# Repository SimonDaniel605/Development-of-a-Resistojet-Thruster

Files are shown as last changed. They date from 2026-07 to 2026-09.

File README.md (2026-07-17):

# Development of a Resistojet Thruster
This repository contains the design, modelling, simulation, and development of a low-power electrothermal resistojet propulsion system for nanosatellite station-keeping and orbital manoeuvring.

The project forms part of an MEng (Electronic Engineering) research project at Stellenbosch University and focuses on developing a compact, efficient, and manufacturable propulsion system capable of providing precise orbital manoeuvring for future small satellite missions.

The work includes analytical modelling, CFD validation, hardware development, electronics, embedded software, and experimental test infrastructure.

## Author
**Simon Daniel**  
MEng Candidate  
Electronic Systems Laboratory (ESL)  
Department of Electrical and Electronic Engineering  
Stellenbosch University

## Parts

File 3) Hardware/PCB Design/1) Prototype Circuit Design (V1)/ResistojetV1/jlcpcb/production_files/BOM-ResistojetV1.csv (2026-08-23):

Comment | Designator | Footprint | LCSC | Quantity
100 | R10,R12,R16,R17,R18,R19,R2,R20,R21,R22,R23,R4,R6,R8 | R_0603_1608Metric | C22775 | 14
100k | R1,R32 | R_0603_1608Metric | C25803 | 2
100n | C3,C6,C7 | C_0603_1608Metric | C14663 | 3
100n | C10,C11,C12,C13,C17,C18,C22,C28,C29,C30,C31,C32 | C_0402_1005Metric | C1525 | 12
10k | R11,R13,R14,R24,R29,R3,R30,R5,R7,R9 | R_0603_1608Metric | C25804 | 10
10n | C14,C19,C24,C25,C26,C27 | C_0402_1005Metric | C15195 | 6
10u | C8,C9 | C_0805_2012Metric | C15850 | 2
10u | C2 | C_0805_2012Metric | C440198 | 1
120R | FB1,FB2 | L_0603_1608Metric | C14709 | 2
1N5819WS | D10,D11,D12,D13,D14,D15,D8,D9 | D_SOD-323 | C191023 | 8
1k | R33 | R_0603_1608Metric | C21190 | 1
1n | C33 | C_0603_1608Metric | C1588 | 1
1u | C15,C16,C20,C21 | C_0603_1608Metric | C15849 | 4
220n | C23 | C_0603_1608Metric | C21120 | 1
22u | C4,C5 | C_0805_2012Metric | C45783 | 2
330 | R26,R27,R28 | R_0603_1608Metric | C23138 | 3
680R | R15,R34,R35 | R_0603_1608Metric | C23228 | 3
68k | R31 | R_0603_1608Metric | C23231 | 1
AMS1117-3.3 | U1 | SOT-223-3_TabPin2 | C6186 | 1
AO3400A | Q2,Q3,Q4,Q5,Q6,Q7 | SOT-23 | C20917 | 6
AP63205WU | U2 | TSOT-23-6 | C2071056 | 1
LED | D16,D17 | LED_0603_1608Metric | C2286 | 2
LED | D18,D7 | LED_0603_1608Metric | C2290 | 2
SS14 | D3,D4,D5,D6 | D_SMA | C2480 | 4
SW_Push | SW1 | SW-SMD_L3.9-W3.0-P4.45 | C720477 | 1

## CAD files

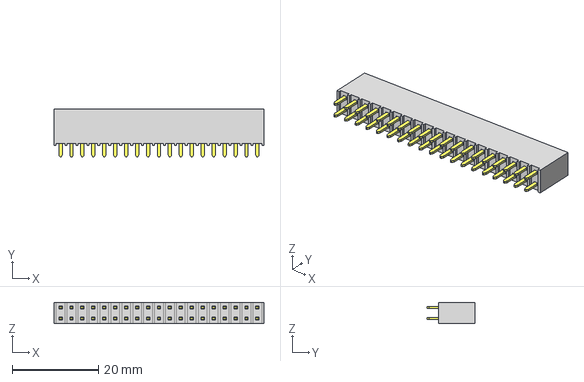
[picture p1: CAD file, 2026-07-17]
3) Hardware/PCB Design/1) Prototype Circuit Design (V1)/Test PCB/ThrusterPrototype/SSW-119-01-F-D.stp
48.8 x 11.2 x 4.95 mm
T1SSW-119-01-F-D
P2SSW-119-01-F-D

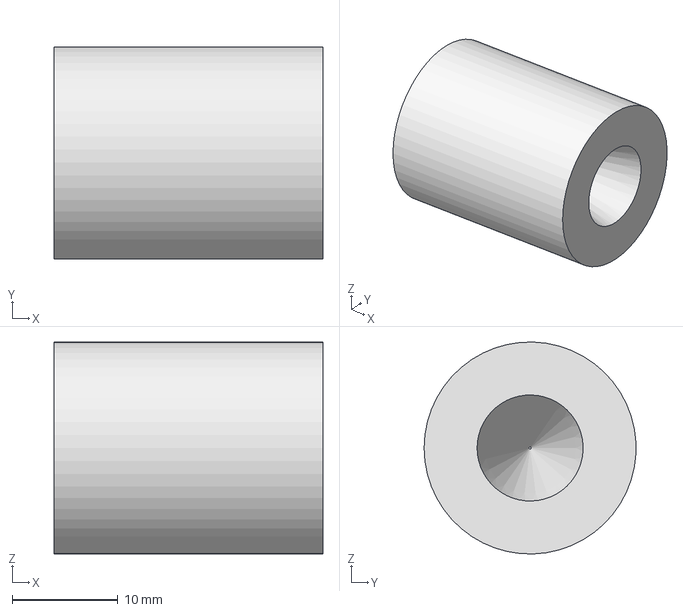
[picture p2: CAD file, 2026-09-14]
3) Hardware/Resistojet Design/ResistojetV2/Nozzle_JLC.step
25.4 x 20.0 x 20.0 mm

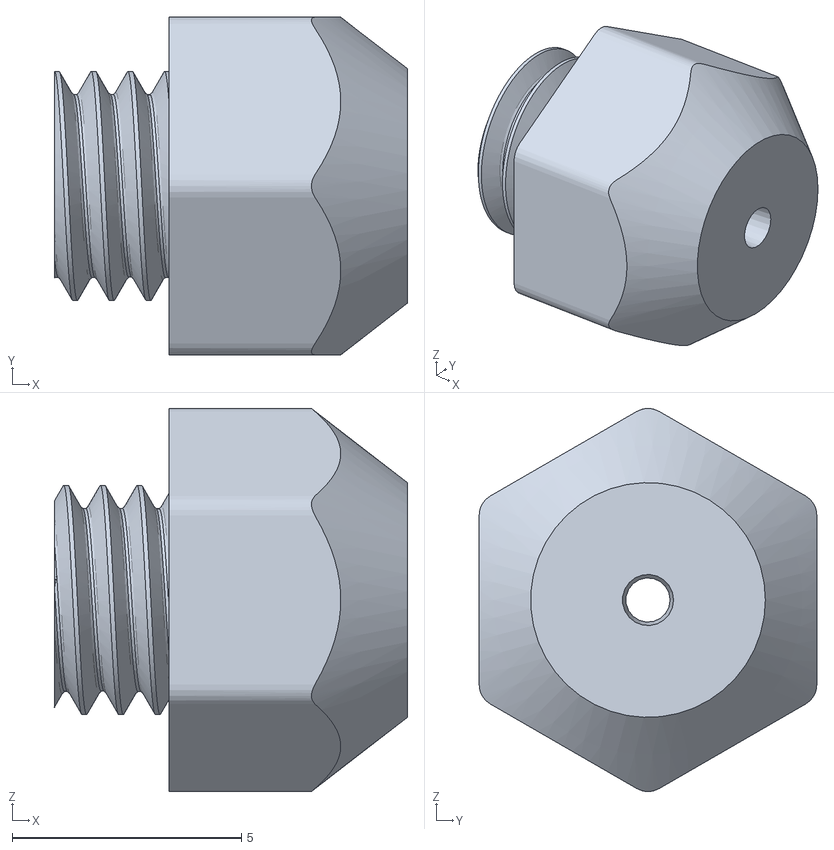
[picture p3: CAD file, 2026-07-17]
3) Hardware/Resistojet Design/Test Nozzles/Jansen's Nozzle Replacements/Redesigned_5.stl
7.69 x 7.36 x 8.35

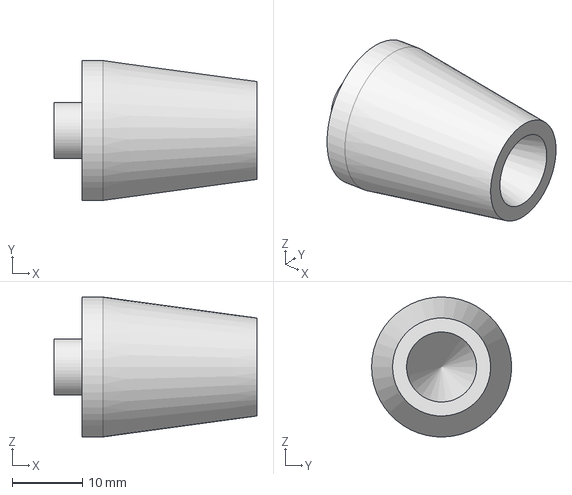
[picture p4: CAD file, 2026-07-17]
3) Hardware/Resistojet Design/Test Nozzles/Nozzle.stp
29.0 x 20.0 x 20.0 mm

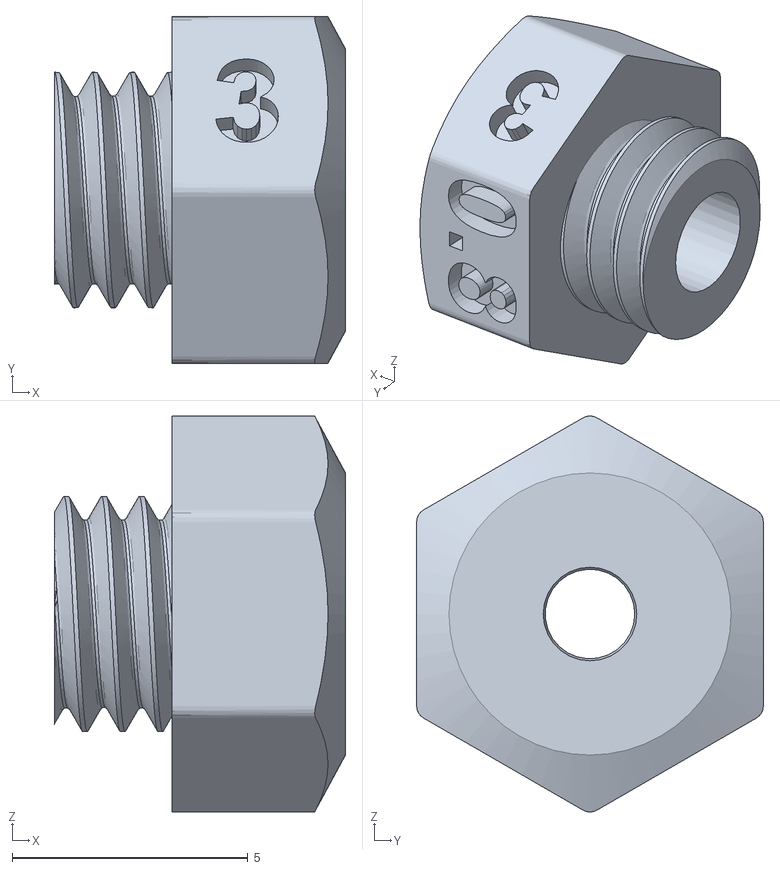
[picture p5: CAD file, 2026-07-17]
3) Hardware/Resistojet Design/Test Nozzles/Test Bench Nozzles/3 bar/Redesigned3_0.8.stl
6.18 x 7.36 x 8.41

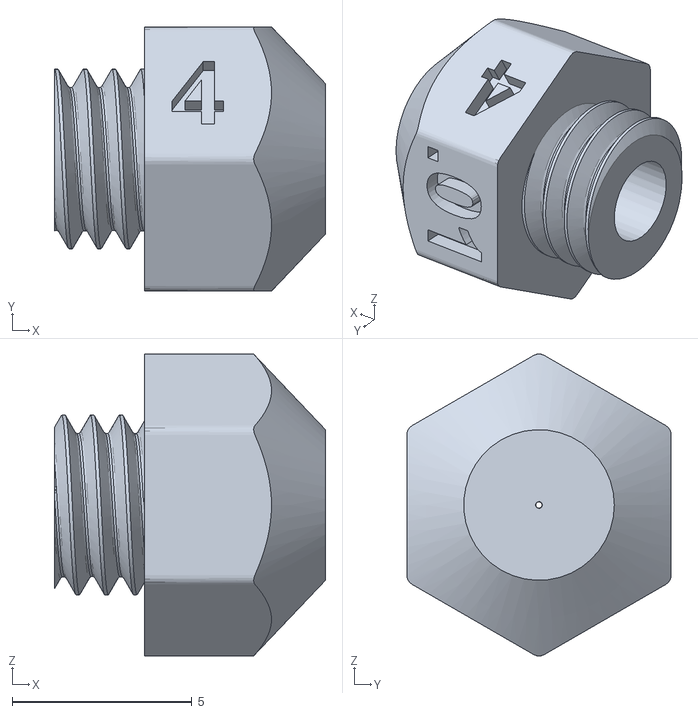
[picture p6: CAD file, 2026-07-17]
3) Hardware/Resistojet Design/Test Nozzles/Test Bench Nozzles/4 bar/Redesigned4_0.01.stl
7.55 x 7.36 x 8.41

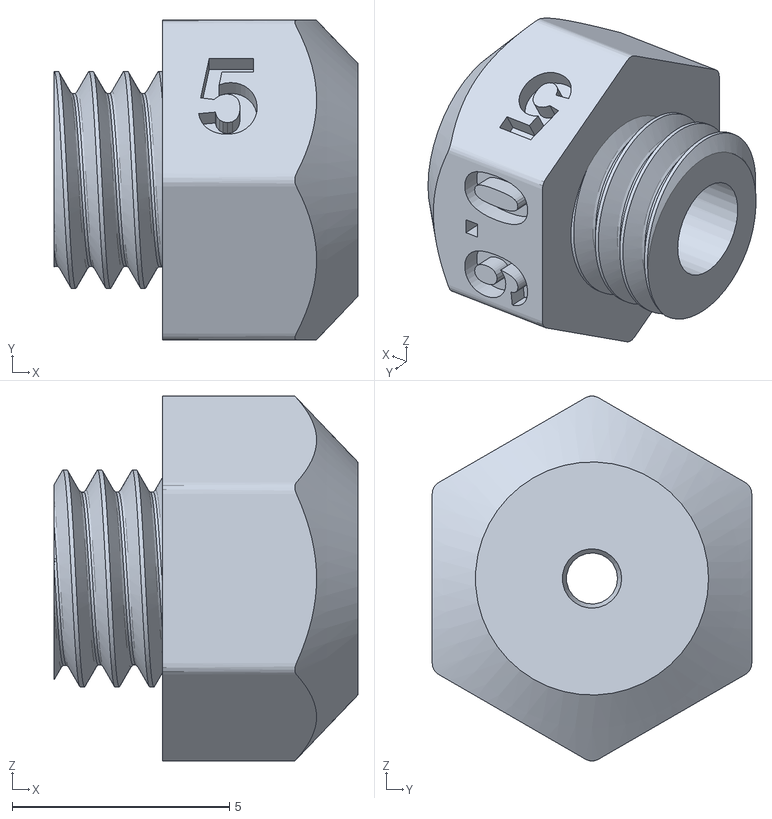
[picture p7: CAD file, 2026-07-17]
3) Hardware/Resistojet Design/Test Nozzles/Test Bench Nozzles/5 bar/Redesigned5_0.6.stl
7.00 x 7.36 x 8.41

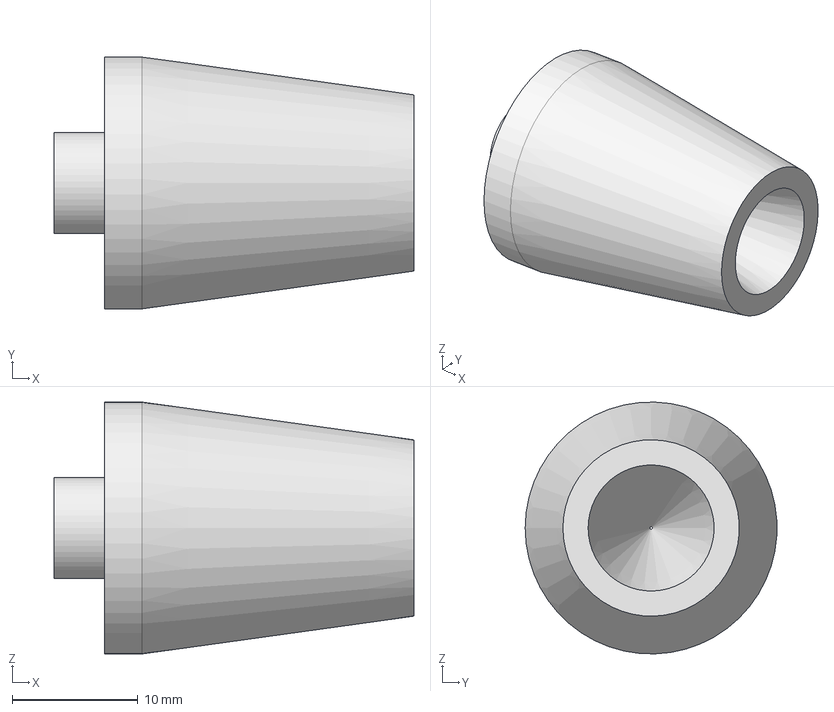
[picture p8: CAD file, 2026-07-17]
3) Hardware/Resistojet Design/ResistojetV2/Nozzle_axial.step
28.6 x 20.0 x 20.0 mm

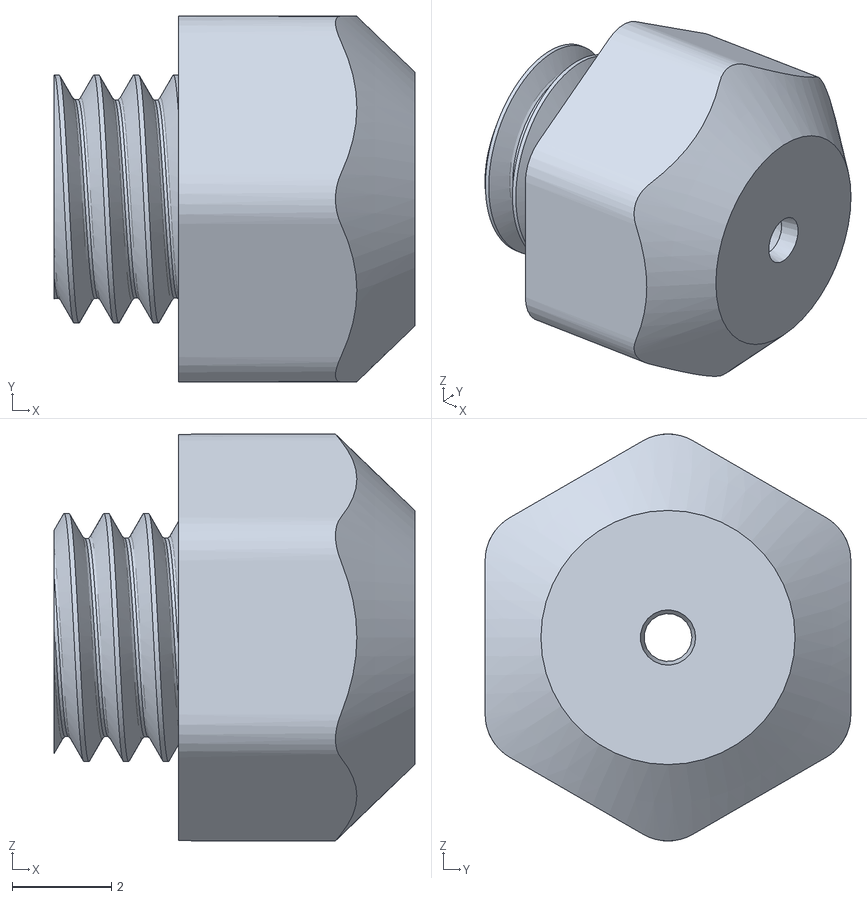
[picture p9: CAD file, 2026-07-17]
3) Hardware/Resistojet Design/Test Nozzles/Jansen's Nozzle Replacements/Redesigned_10.stl
7.26 x 7.36 x 8.19

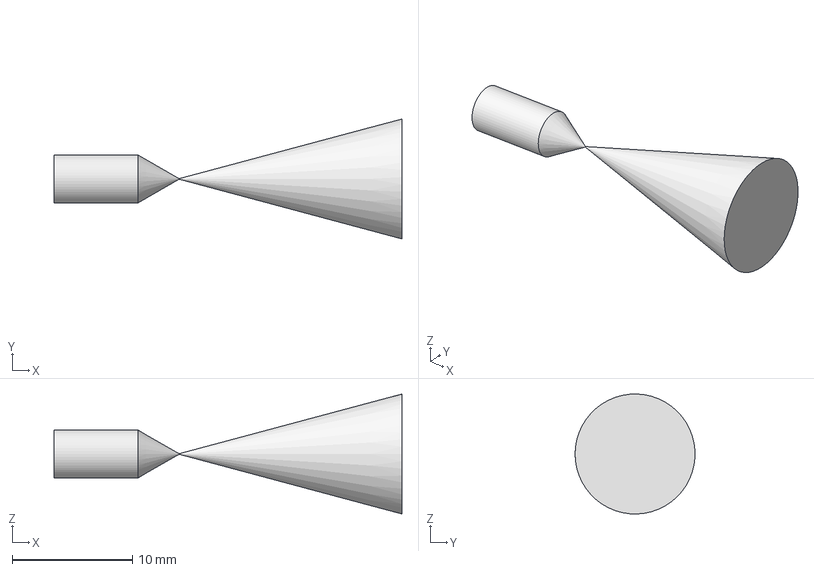
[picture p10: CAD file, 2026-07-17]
3) Hardware/Resistojet Design/Test Nozzles/NozzlePath.stp
29.0 x 9.99 x 10.00 mm

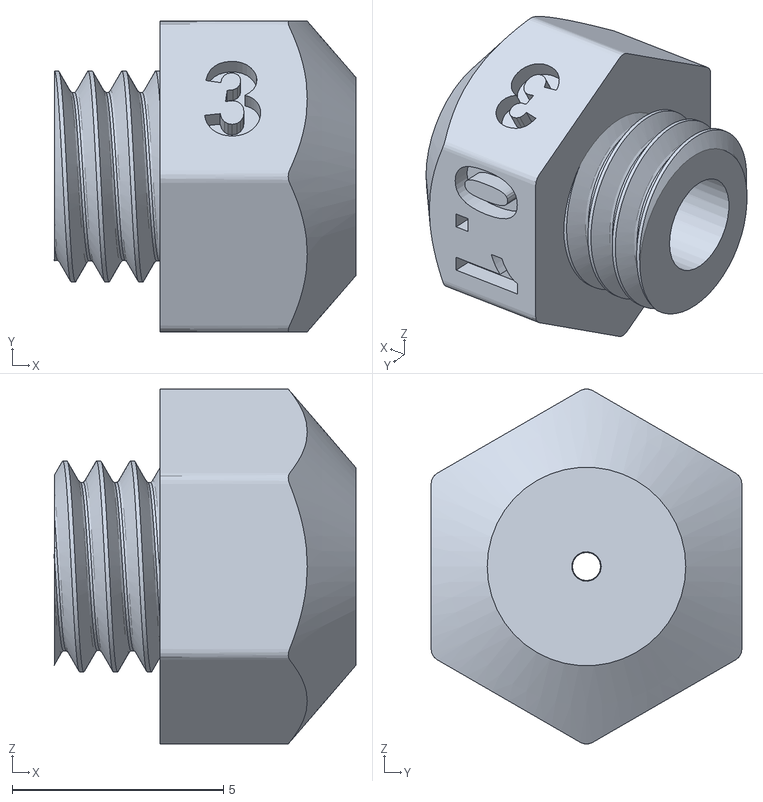
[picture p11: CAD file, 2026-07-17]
3) Hardware/Resistojet Design/Test Nozzles/Test Bench Nozzles/3 bar/Redesigned3_0.1.stl
7.14 x 7.36 x 8.41

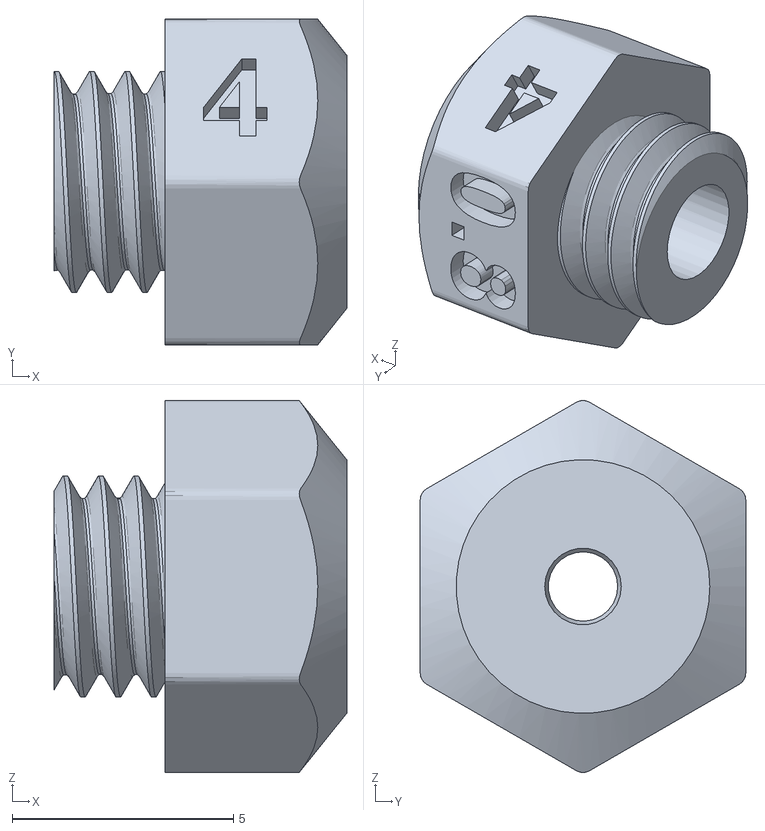
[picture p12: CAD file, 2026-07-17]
3) Hardware/Resistojet Design/Test Nozzles/Test Bench Nozzles/4 bar/Redesigned4_0.8.stl
6.61 x 7.36 x 8.41

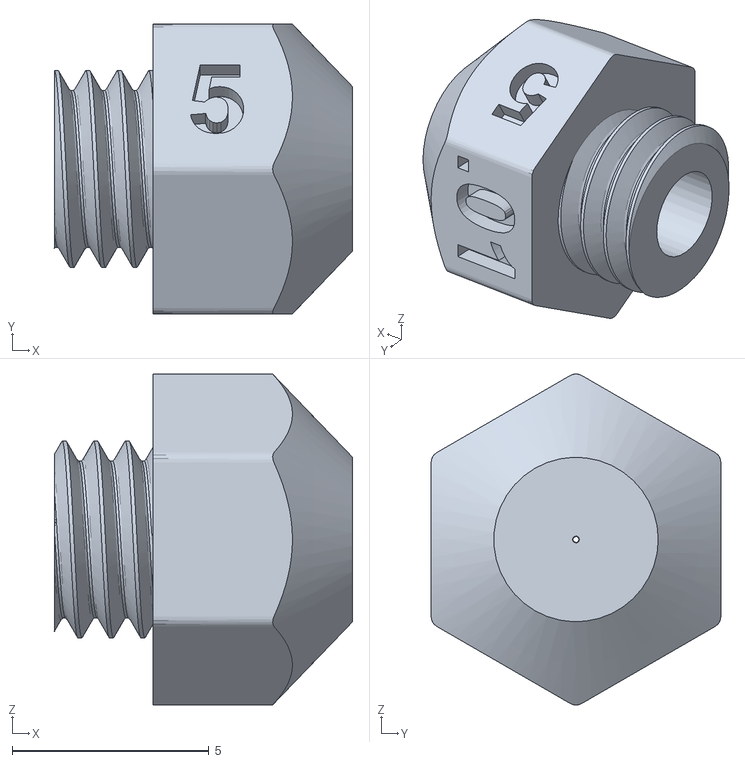
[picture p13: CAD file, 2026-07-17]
3) Hardware/Resistojet Design/Test Nozzles/Test Bench Nozzles/5 bar/Redesigned5_0.01.stl
7.58 x 7.36 x 8.41

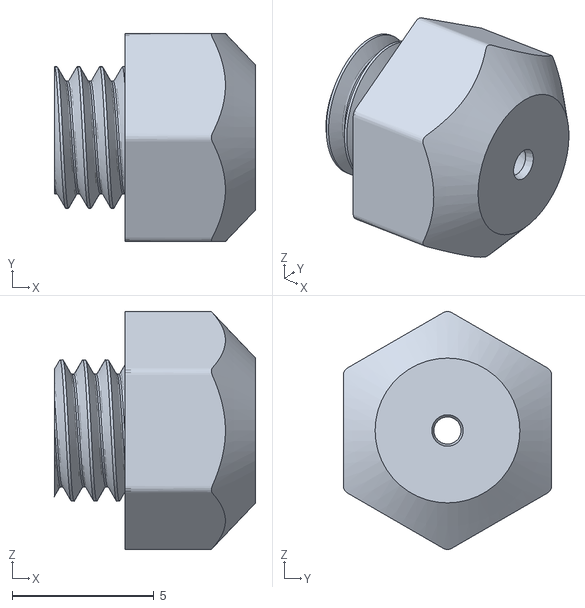
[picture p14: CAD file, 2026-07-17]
3) Hardware/Resistojet Design/Test Nozzles/Jansen's Nozzle Replacements/Redesigned_15.stl
7.11 x 7.36 x 8.41

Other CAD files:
3) Hardware/Resistojet Design/Test Nozzles/Test Bench Nozzles/3 bar/Redesigned3_0.6.stl
3) Hardware/Resistojet Design/Test Nozzles/Test Bench Nozzles/4 bar/Redesigned4_0.4.stl
3) Hardware/Resistojet Design/Test Nozzles/Test Bench Nozzles/5 bar/Redesigned5_1.0.stl
3) Hardware/Resistojet Design/Test Nozzles/Jansen's Nozzle Replacements/Original.stl
3) Hardware/PCB Design/1) Prototype Circuit Design (V1)/Test PCB/ThrusterPrototype/MC00100/MC00100.step
3) Hardware/Resistojet Design/Prototype Design/Heater.ipt
3) Hardware/Resistojet Design/Prototype Design/Mechanical Drawings/Plenum2.idw
3) Hardware/Resistojet Design/Prototype Design/Mechanical Drawings/Plenum2.ipt
3) Hardware/Resistojet Design/Prototype Design/Plenum.ipt
3) Hardware/Resistojet Design/ResistojetV1/0.4 nozzle.ipt
3) Hardware/Resistojet Design/ResistojetV1/100g_load_cell.ipt
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

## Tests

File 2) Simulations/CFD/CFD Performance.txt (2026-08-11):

CFD performance for difference viscous models:
g = 9.80665 m/s^2

Baseline Analytical Nozzle Equations (MATLAB Simulation):
Me    = 5.21
Ve    = 862.09 m/s
Pe    = 16.754 Pa
Te    = 315.43 K
Pspace= 1e-7 Pa
m_dot = 4.413e-05 kg/s
F     = 39.36 mN
Isp   = 90.95 s

Laminar:
Me    = 3.96       (mass weighted average)
Ve    = 650.35 m/s (mass weighted average)
Pe    = 28.976 Pa  (area weighted average)
Pspace= 1 Pa
m_dot = 4.458e-05 kg/s
F     = 31.16 mN
Isp   = 71.27 s

SST K-Omega:
Me    = 3.96       (mass weighted average)
Ve    = 655.69 m/s (mass weighted average)
Pe    = 28.850 Pa  (area weighted average)
Pspace= 1 Pa
m_dot = 4.420e-05 kg/s
F     = 31.14 mN
Isp   = 71.83 s

First 2D (12000):
SST K-Omega:
Me    = 3.97       (mass weighted average)
Ve    = 677.37 m/s (mass weighted average)
Pe    = 30.688 Pa  (area weighted average)
Te    = 358.54 K   (mass weighted average)
Pspace= 1e-7 Pa    (change back to 1)
m_dot = 4.368e-05 kg/s
F     = 31.92 mN
Isp   = 74.52 s

Second 2D (35000):
SST K-Omega (Roughness Height = 0 m):
Me    = 4.05       (mass weighted average)
Ve    = 690.61 m/s (mass weighted average)
Pe    = 29.295 Pa  (area weighted average)
Te    = 363.87 K   (mass weighted average)
Pspace= 1 Pa
m_dot = 4.234e-05 kg/s
F     = 31.46 mN
Isp   = 75.77 s

Third 2D (10000):
Invicid:
Me    = 5.54       (mass weighted average)
Ve    = 832.81 m/s (mass weighted average)
Pe    = 13.414 Pa  (area weighted average)
Te    = 255.87 K   (mass weighted average)
Pspace= 1 Pa
m_dot = 4.208e-05 kg/s
F     = 36.02 mN
Isp   = 87.29 s

Fourth 2D (35000):
SST K-Omega (Roughness Height = 1e-5 m):
Me    = 4.04       (mass weighted average)
Ve    = 689.35 m/s (mass weighted average)
Pe    = 29.278 Pa  (area weighted average)
Te    = 364.87 K   (mass weighted average)
Pspace= 1 Pa
m_dot = 4.222e-05 kg/s
F     = 31.33 mN
Isp   = 75.66 s

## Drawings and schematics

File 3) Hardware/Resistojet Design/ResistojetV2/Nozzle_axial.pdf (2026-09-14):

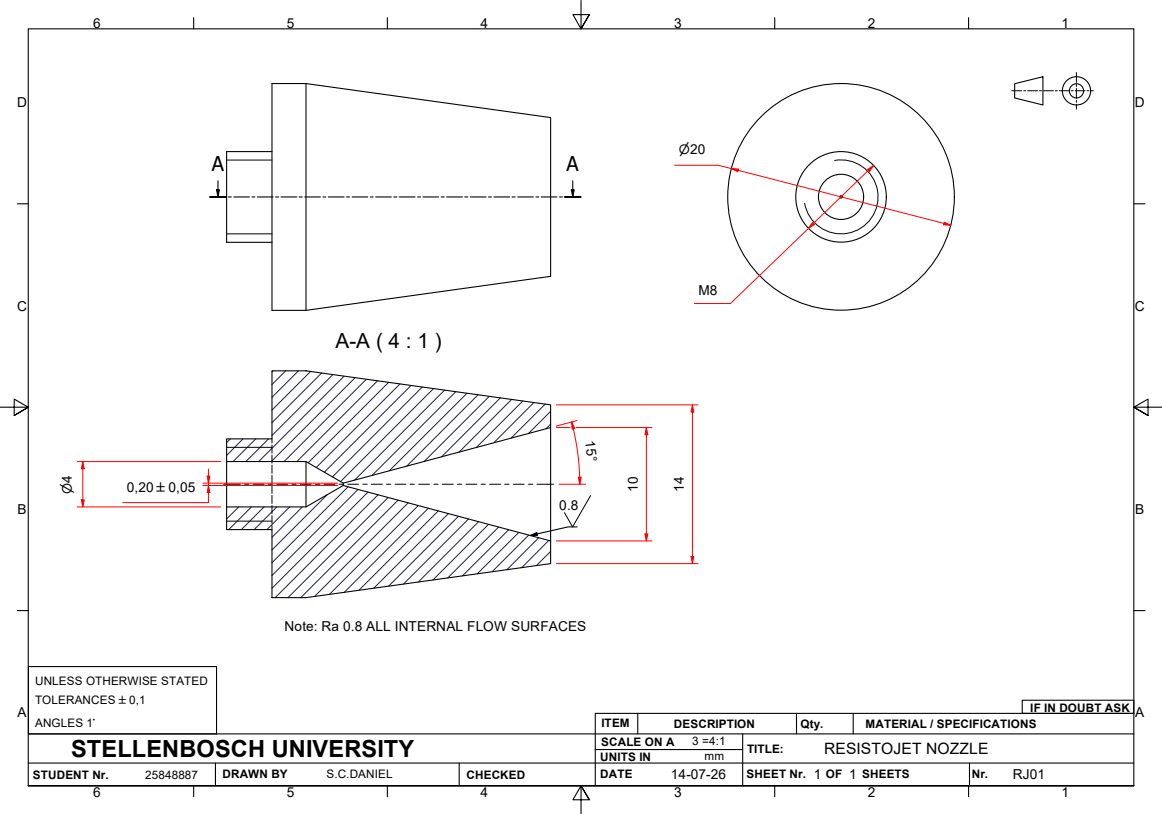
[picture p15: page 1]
STUDENT Nr.; DRAWN BY; CHECKED; UNITS IN; SHEET Nr.; SHEETS

Note: Ra 0.8 ALL INTERNAL FLOW SURFACES

UNLESS OTHERWISE STATED
TOLERANCES `0,1
ANGLES 1~

IF IN DOUBT ASK

ITEM | DESCRIPTION | Qty. | MATERIAL / SPECIFICATIONS

STELLENBOSCH UNIVERSITY | SCALE ON A 3 =4:1 | TITLE: RESISTOJET NOZZLE

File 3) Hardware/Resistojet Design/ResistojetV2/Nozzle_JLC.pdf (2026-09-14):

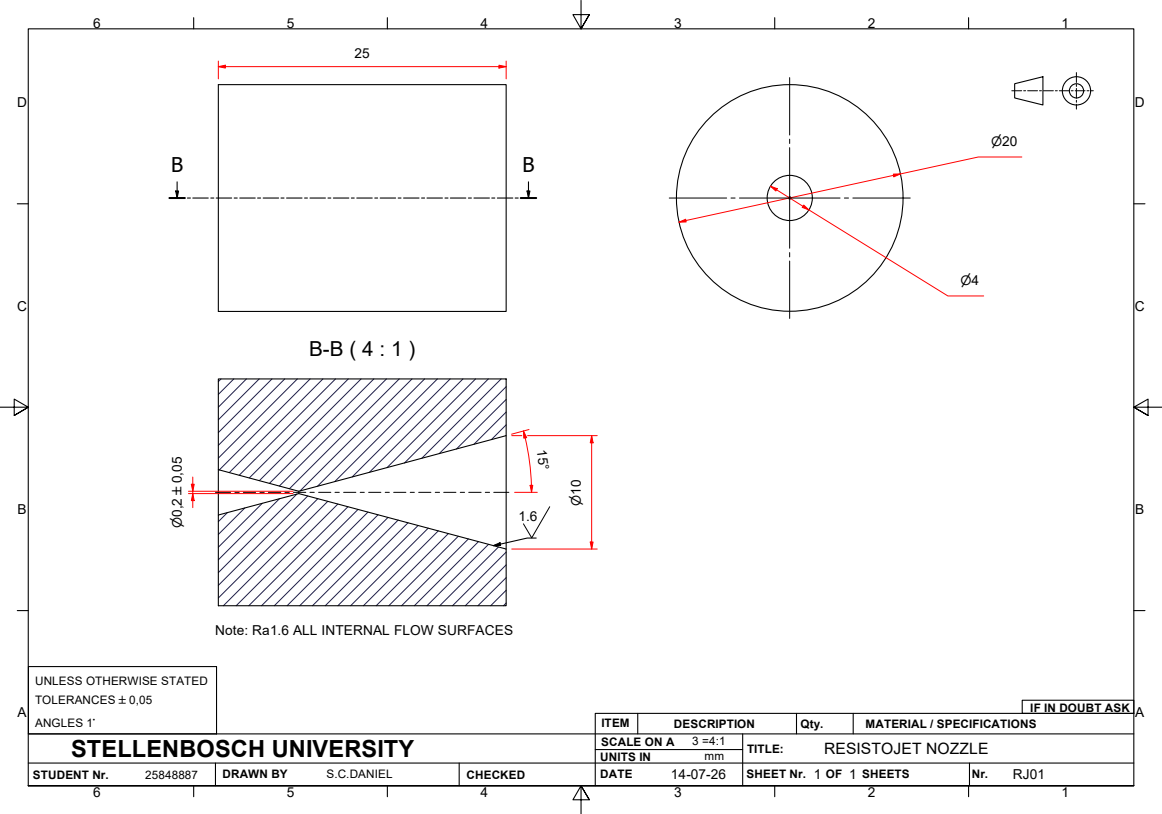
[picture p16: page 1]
STUDENT Nr.; DRAWN BY; CHECKED; UNITS IN; SHEET Nr.; SHEETS

Note: Ra1.6 ALL INTERNAL FLOW SURFACES

UNLESS OTHERWISE STATED
TOLERANCES `0,05
ANGLES 1~

IF IN DOUBT ASK

ITEM | DESCRIPTION | Qty. | MATERIAL / SPECIFICATIONS

STELLENBOSCH UNIVERSITY | SCALE ON A 3 =4:1 | TITLE: RESISTOJET NOZZLE

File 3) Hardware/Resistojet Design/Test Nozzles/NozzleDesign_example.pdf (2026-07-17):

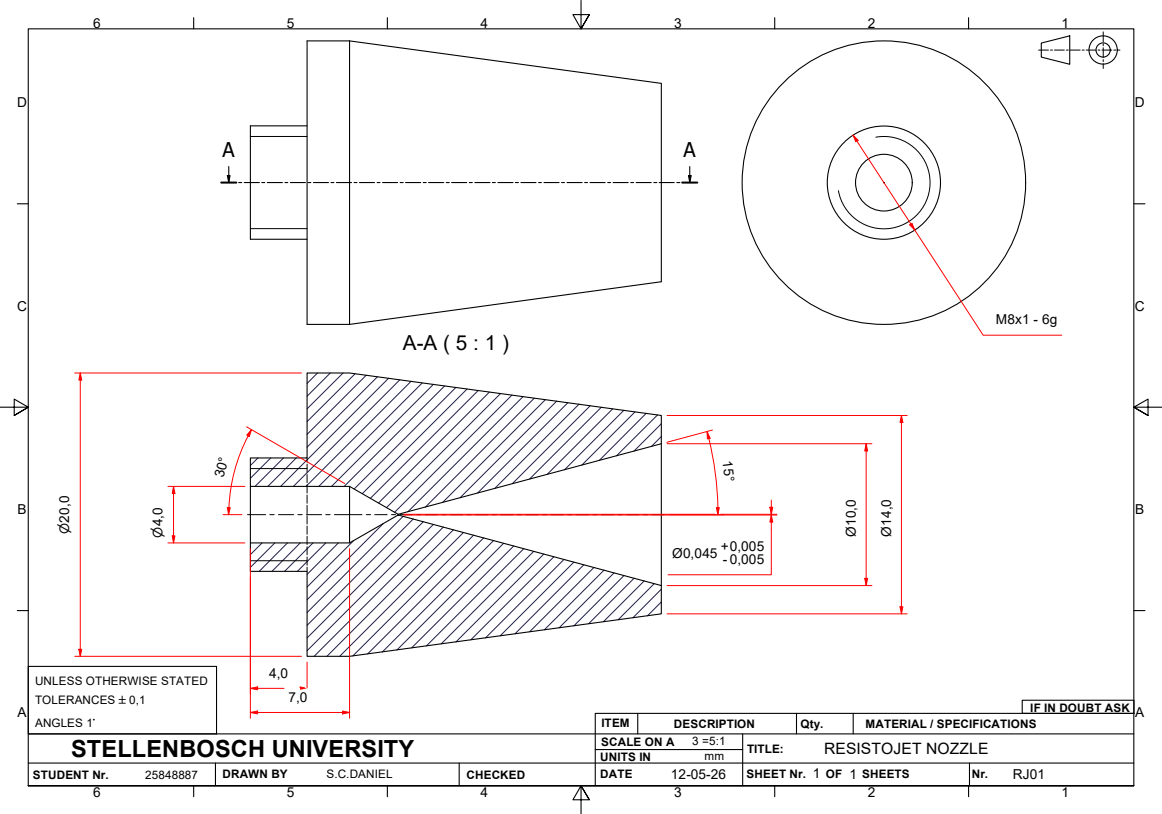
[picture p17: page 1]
STUDENT Nr.; DRAWN BY; CHECKED; UNITS IN; SHEET Nr.; SHEETS

UNLESS OTHERWISE STATED
TOLERANCES `0,1
ANGLES 1~

IF IN DOUBT ASK

ITEM | DESCRIPTION | Qty. | MATERIAL / SPECIFICATIONS

STELLENBOSCH UNIVERSITY | SCALE ON A 3 =5:1 | TITLE: RESISTOJET NOZZLE

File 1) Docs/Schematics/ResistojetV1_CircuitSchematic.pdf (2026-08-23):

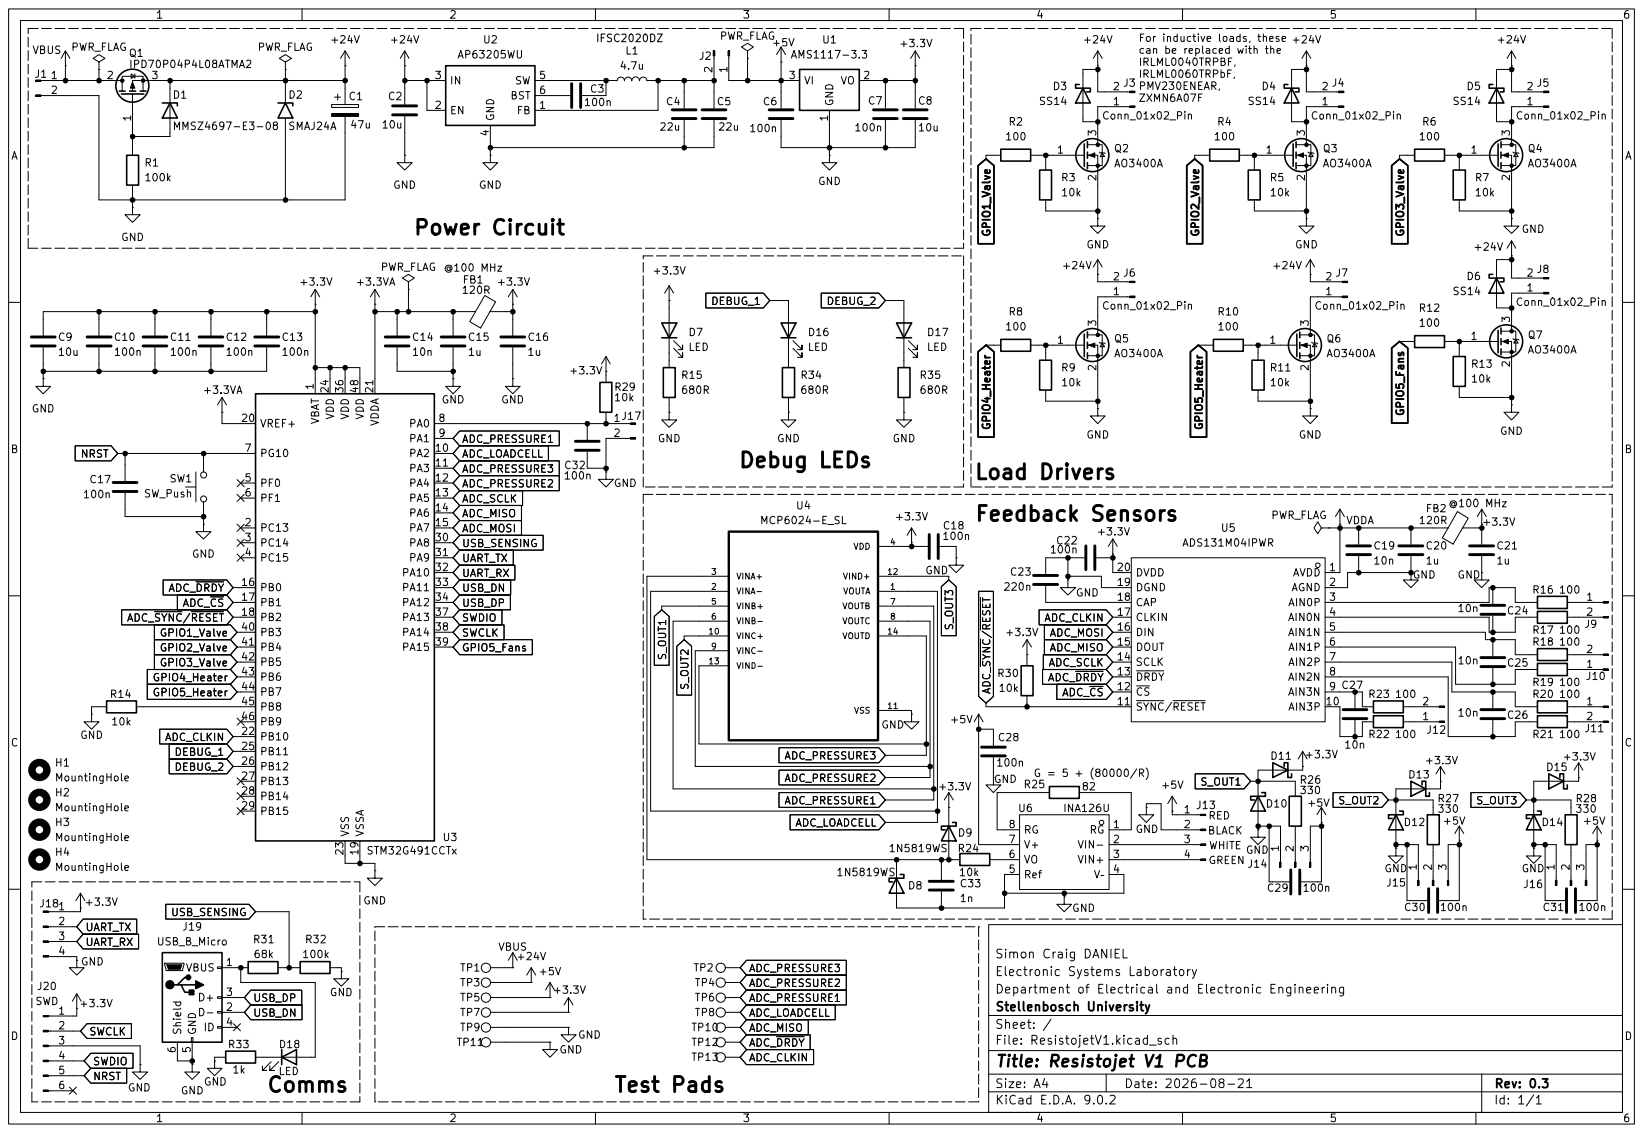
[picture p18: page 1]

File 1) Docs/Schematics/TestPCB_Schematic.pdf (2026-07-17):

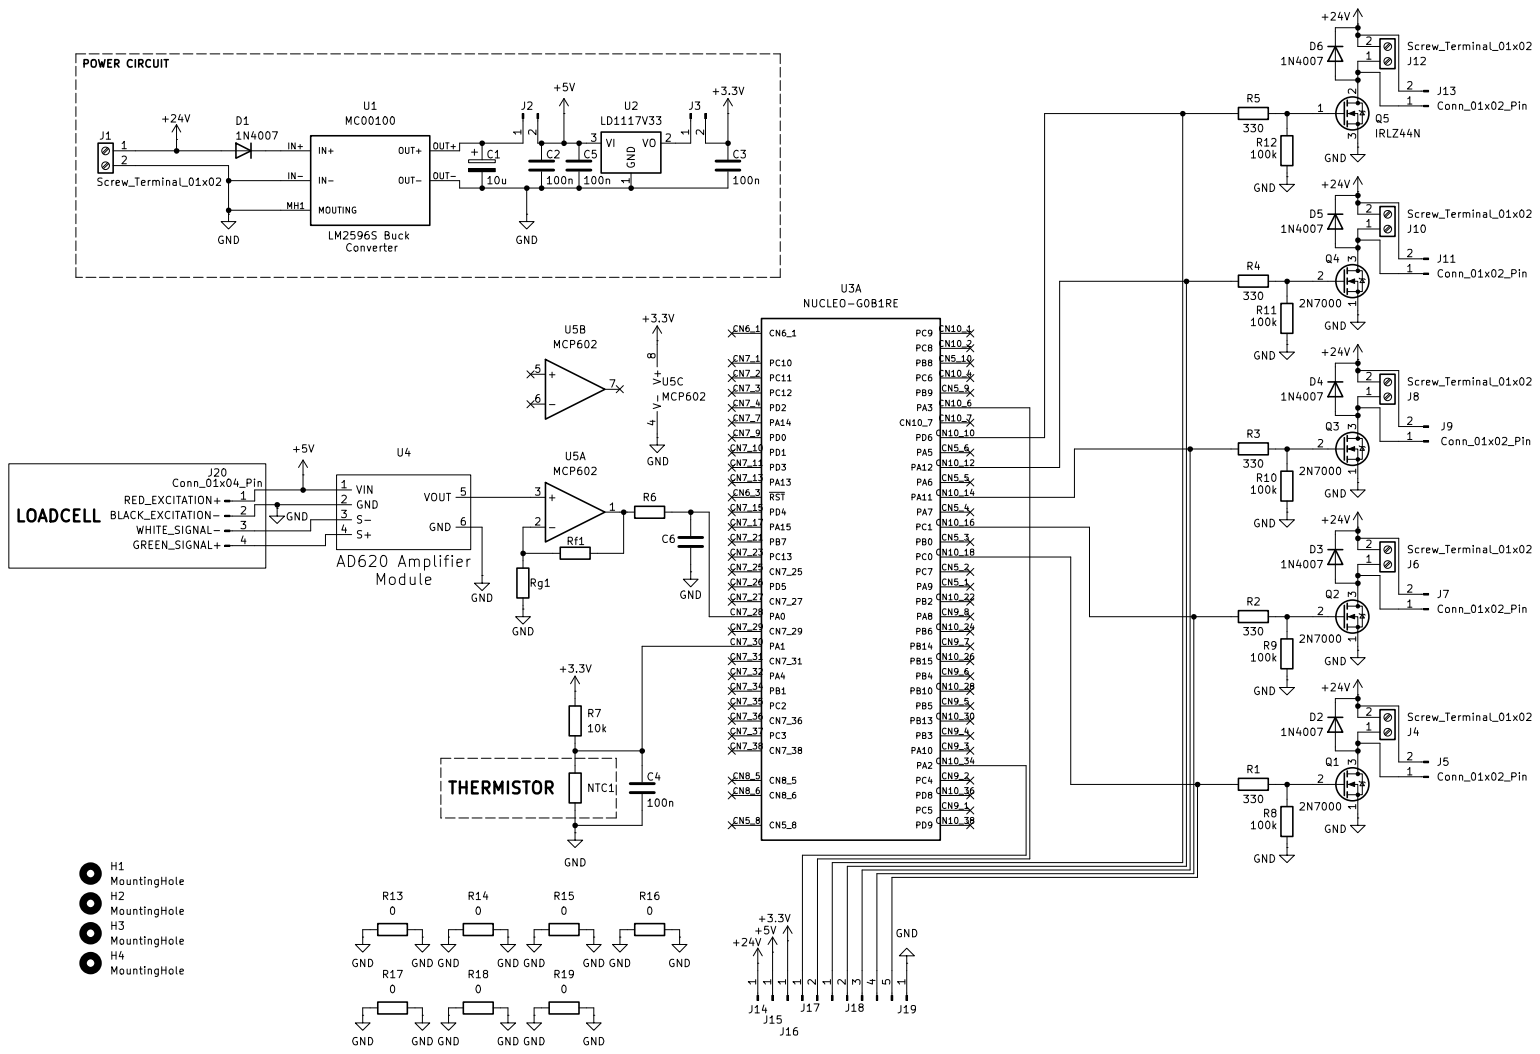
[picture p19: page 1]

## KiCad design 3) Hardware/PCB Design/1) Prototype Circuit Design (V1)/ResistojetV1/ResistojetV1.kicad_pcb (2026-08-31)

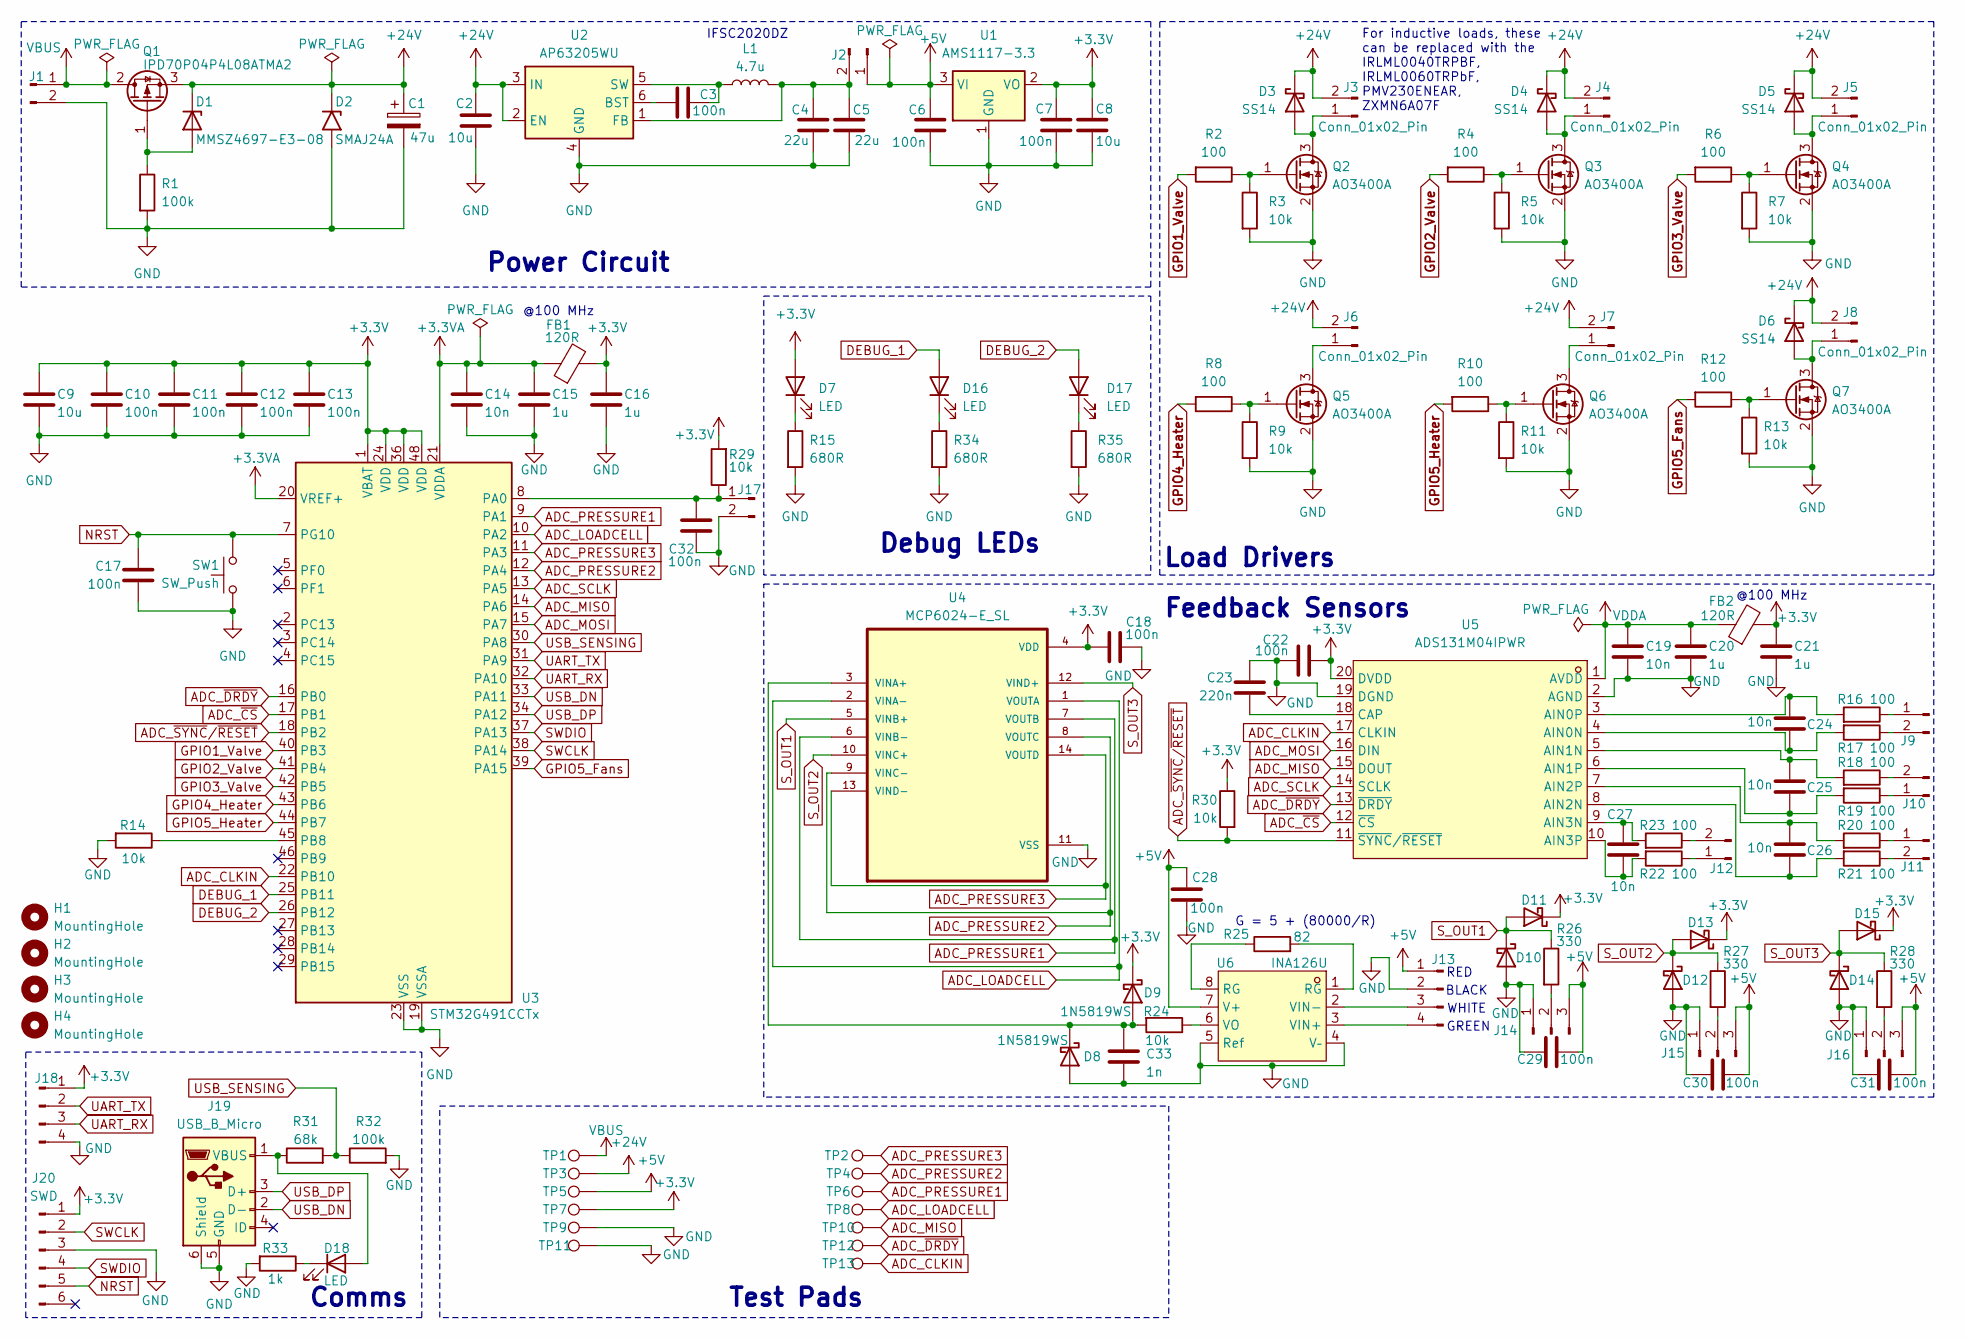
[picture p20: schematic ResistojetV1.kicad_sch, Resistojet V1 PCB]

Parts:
C1: 47u; CP_Elec_6.3x7.7
C2, C8, C9: 10u; C_0805_2012Metric
C3, C6, C7: 100n; C_0603_1608Metric
C4, C5: 22u; C_0805_2012Metric
C10, C11, C12, C13, C17, C18, C22, C28, C29, C30, C31, C32: 100n; C_0402_1005Metric
C14, C19, C24, C25, C26, C27: 10n; C_0402_1005Metric
C15, C16, C20, C21: 1u; C_0603_1608Metric
C23: 220n; C_0603_1608Metric
C33: 1n; C_0603_1608Metric
D1: MMSZ4697-E3-08; D_SOD-123
D2: SMAJ24A; D_SMA
D3, D4, D5, D6: SS14; D_SMA
D7, D16, D17, D18: LED; LED_0603_1608Metric
D8, D9, D10, D11, D12, D13, D14, D15: 1N5819WS; D_SOD-323
FB1, FB2: 120R; L_0603_1608Metric
H1, H2, H3, H4: MountingHole; MountingHole_3.2mm_M3
J1, J6, J7: Conn_01x02_Pin; JST_VH_B2P-VH_1x02_P3.96mm_Vertical
J2: Conn_01x02_Pin; PinHeader_1x02_P2.54mm_Vertical
J3, J4, J5, J8, J9, J10, J11, J12, J17: Conn_01x02_Pin; JST_PH_B2B-PH-K_1x02_P2.00mm_Vertical
J13, J18: Conn_01x04_Pin; JST_PH_B4B-PH-K_1x04_P2.00mm_Vertical
J14, J15, J16: Conn_01x03_Pin; JST_PH_B3B-PH-K_1x03_P2.00mm_Vertical
J19: USB_B_Micro; USB_Micro-B_Molex-105017-0001
J20: SWD; JST_PH_B6B-PH-K_1x06_P2.00mm_Vertical
L1: 4.7u; L_APV_ANR5040
Q1: IPD70P04P4L08ATMA2; TO-252-3_TabPin2
Q2, Q3, Q4, Q5, Q6, Q7: AO3400A; SOT-23
R1, R32: 100k; R_0603_1608Metric
R2, R4, R6, R8, R10, R12, R16, R17, R18, R19, R20, R21, R22, R23: 100; R_0603_1608Metric
R3, R5, R7, R9, R11, R13, R14, R24, R29, R30: 10k; R_0603_1608Metric
R15, R34, R35: 680R; R_0603_1608Metric
R25: 82; R_0603_1608Metric
R26, R27, R28: 330; R_0603_1608Metric
R31: 68k; R_0603_1608Metric
R33: 1k; R_0603_1608Metric
SW1: SW_Push; SW-SMD_L3.9-W3.0-P4.45
TP1, TP2, TP3, TP4, TP5, TP6, TP7, TP8, TP9, TP10, TP11, TP12, TP13: TestPoint; TestPoint_Pad_D1.0mm
U1: AMS1117-3.3; SOT-223-3_TabPin2
U2: AP63205WU; TSOT-23-6
U3: STM32G491CCTx; LQFP-48_7x7mm_P0.5mm
U4: MCP6024-E_SL; SOIC127P600X175-14N
U5: ADS131M04IPWR; TSSOP-20_L6.5-W4.4-P0.65-LS6.4-BL; MPN ADS131M04IPWR; LCSC Part C2862562
U6: INA126U; SOIC-8_L4.9-W3.9-P1.27-LS6.0-BL; MPN INA126U; LCSC Part C1346079

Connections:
+3.3V: C7.2, C8.2, C9.1, C10.1, C11.1, C12.1, C13.1, C16.1, C18.1, C21.1, C22.2, D7.2 (A), D9.1 (K), D11.1 (K), D13.1 (K), D15.1 (K), FB1.2, FB2.2, J18.1, J20.1, R29.2, R30.1, TP7.1, U1.2 (VO), U3.1 (VBAT), U3.24 (VDD), U3.36 (VDD), U3.48 (VDD), U4.4 (VDD), U5.20 (DVDD)
+3.3VA: C14.1, C15.1, FB1.1, U3.20 (VREF+), U3.21 (VDDA)
+5V: C6.1, C28.1, C29.1, C30.1, C31.1, J2.1, J13.1, J14.3, J15.3, J16.3, TP5.1, U1.3 (VI), U6.7 (V+)
+24V: C1.1, C2.1, D1.1 (K), D2.1 (A1), D3.1 (K), D4.1 (K), D5.1 (K), D6.1 (K), J3.2, J4.2, J5.2, J6.2, J7.2, J8.2, Q1.3 (S), TP3.1, U2.2 (EN), U2.3 (IN)
ADC_CLKIN: TP13.1, U3.22 (PB10), U5.17 (CLKIN)
ADC_LOADCELL: TP8.1, U3.10 (PA2), U4.1 (VOUTA), U4.2 (VINA-)
ADC_MISO: TP10.1, U3.14 (PA6), U5.15 (DOUT)
ADC_MOSI: U3.15 (PA7), U5.16 (DIN)
ADC_PRESSURE1: TP6.1, U3.9 (PA1), U4.6 (VINB-), U4.7 (VOUTB)
ADC_PRESSURE2: TP4.1, U3.12 (PA4), U4.8 (VOUTC), U4.9 (VINC-)
ADC_PRESSURE3: TP2.1, U3.11 (PA3), U4.13 (VIND-), U4.14 (VOUTD)
ADC_SCLK: U3.13 (PA5), U5.14 (SCLK)
ADC_~CS: U3.17 (PB1), U5.12 (~CS)
ADC_~DRDY: TP12.1, U3.16 (PB0), U5.13 (~DRDY)
ADC_~SYNC/~RESET: R30.2, U3.18 (PB2), U5.11 (~SYNC/~RESET)
DEBUG_1: D16.2 (A), U3.25 (PB11)
DEBUG_2: D17.2 (A), U3.26 (PB12)
GND: C1.2, C2.2, C4.2, C5.2, C6.2, C7.1, C8.1, C9.2, C10.2, C11.2, C12.2, C13.2, C14.2, C15.2, C16.2, C17.2, C18.2, C19.2, C20.2, C21.2, C22.1, C23.1, C28.2, C29.2, C30.2, C31.2, C32.1, C33.2, D2.2 (A2), D8.2 (A), D10.2 (A), D12.2 (A), D14.2 (A), J1.2, J13.2, J14.1, J15.1, J16.1, J17.2, J18.4, J19.5 (GND), J19.6 (Shield), J20.3, Q2.2 (S), Q3.2 (S), Q4.2 (S), Q5.2 (S), Q6.2 (S), Q7.2 (S), R1.2, R3.2, R5.2, R7.2, R9.2, R11.2, R13.2, R14.2, R15.2, R32.2, R33.2, R34.2, R35.2, SW1.2, TP9.1, TP11.1, U1.1 (GND), U2.4 (GND), U3.19 (VSSA), U3.23 (VSS), U3.35 (VSS), U3.47 (VSS), U4.11 (VSS), U5.2 (AGND), U5.19 (DGND), U6.4 (V–), U6.5 (Ref)
GPIO1_Valve: R2.2, U3.40 (PB3)
GPIO2_Valve: R4.2, U3.41 (PB4)
GPIO3_Valve: R6.2, U3.42 (PB5)
GPIO4_Heater: R8.2, U3.43 (PB6)
GPIO5_Fans: R12.2, U3.39 (PA15)
GPIO5_Heater: R10.2, U3.44 (PB7)
NRST: C17.1, J20.5, SW1.1, U3.7 (PG10)
unnamed: D1.2 (A), Q1.1 (G), R1.1
unnamed: D3.2 (A), J3.1, Q2.3 (D)
unnamed: D4.2 (A), J4.1, Q3.3 (D)
unnamed: D5.2 (A), J5.1, Q4.3 (D)
unnamed: D6.2 (A), J8.1, Q7.3 (D)
unnamed: D7.1 (K), R15.1
unnamed: C33.1, D8.1 (K), D9.2 (A), R24.2, U4.3 (VINA+)
unnamed: D16.1 (K), R34.1
unnamed: D17.1 (K), R35.1
unnamed: D18.2 (A), J19.1 (VBUS), R31.1
unnamed: D18.1 (K), R33.1
unnamed: C4.1, C5.1, J2.2, L1.2, U2.1 (FB)
unnamed: J6.1, Q5.3 (D)
unnamed: J7.1, Q6.3 (D)
unnamed: J9.1, R16.1
unnamed: J9.2, R17.1
unnamed: J10.1, R19.1
unnamed: J10.2, R18.1
unnamed: J11.1, R20.1
unnamed: J11.2, R21.1
unnamed: J12.1, R22.1
unnamed: J12.2, R23.1
unnamed: J13.3, U6.2 (VIN-)
unnamed: J13.4, U6.3 (VIN+)
unnamed: J14.2, R26.2
unnamed: J15.2, R27.2
unnamed: J16.2, R28.2
unnamed: C32.2, J17.1, R29.1, U3.8 (PA0)
unnamed: Q2.1 (G), R2.1, R3.1
unnamed: Q3.1 (G), R4.1, R5.1
unnamed: Q4.1 (G), R6.1, R7.1
unnamed: Q5.1 (G), R8.1, R9.1
unnamed: Q6.1 (G), R10.1, R11.1
unnamed: Q7.1 (G), R12.1, R13.1
unnamed: R25.1, U6.8 (RG)
unnamed: R25.2, U6.1 (RG)
unnamed: C3.1, U2.6 (BST)
unnamed: C3.2, L1.1, U2.5 (SW)
unnamed: R14.1, U3.45 (PB8)
unnamed: C24.2, R17.2, U5.4 (AIN0N)
unnamed: C24.1, R16.2, U5.3 (AIN0P)
unnamed: C25.1, R18.2, U5.5 (AIN1N)
unnamed: C25.2, R19.2, U5.6 (AIN1P)
unnamed: C26.2, R21.2, U5.8 (AIN2N)
unnamed: C26.1, R20.2, U5.7 (AIN2P)
unnamed: C27.2, R23.2, U5.9 (AIN3N)
unnamed: C27.1, R22.2, U5.10 (AIN3P)
unnamed: C23.2, U5.18 (CAP)
unnamed: R24.1, U6.6 (VO)
SWCLK: J20.2, U3.38 (PA14)
SWDIO: J20.4, U3.37 (PA13)
S_OUT1: D10.1 (K), D11.2 (A), R26.1, U4.5 (VINB+)
S_OUT2: D12.1 (K), D13.2 (A), R27.1, U4.10 (VINC+)
S_OUT3: D14.1 (K), D15.2 (A), R28.1, U4.12 (VIND+)
UART_RX: J18.3, U3.32 (PA10)
UART_TX: J18.2, U3.31 (PA9)
USB_DN: J19.2 (D-), U3.33 (PA11)
USB_DP: J19.3 (D+), U3.34 (PA12)
USB_SENSING: R31.2, R32.1, U3.30 (PA8)
VBUS: J1.1, Q1.2 (D), TP1.1
VDDA: C19.1, C20.1, FB2.1, U5.1 (AVDD)

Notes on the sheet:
WHITE
G = 5 + (80000/R)
Comms
@100 MHz
Test Pads
Debug LEDs
Feedback Sensors
RED
Power Circuit
IFSC2020DZ
Load Drivers
GREEN
For inductive loads, these can be replaced with the IRLML0040TRPBF, IRLML0060TRPbF, PMV230ENEAR, ZXMN6A07F
BLACK

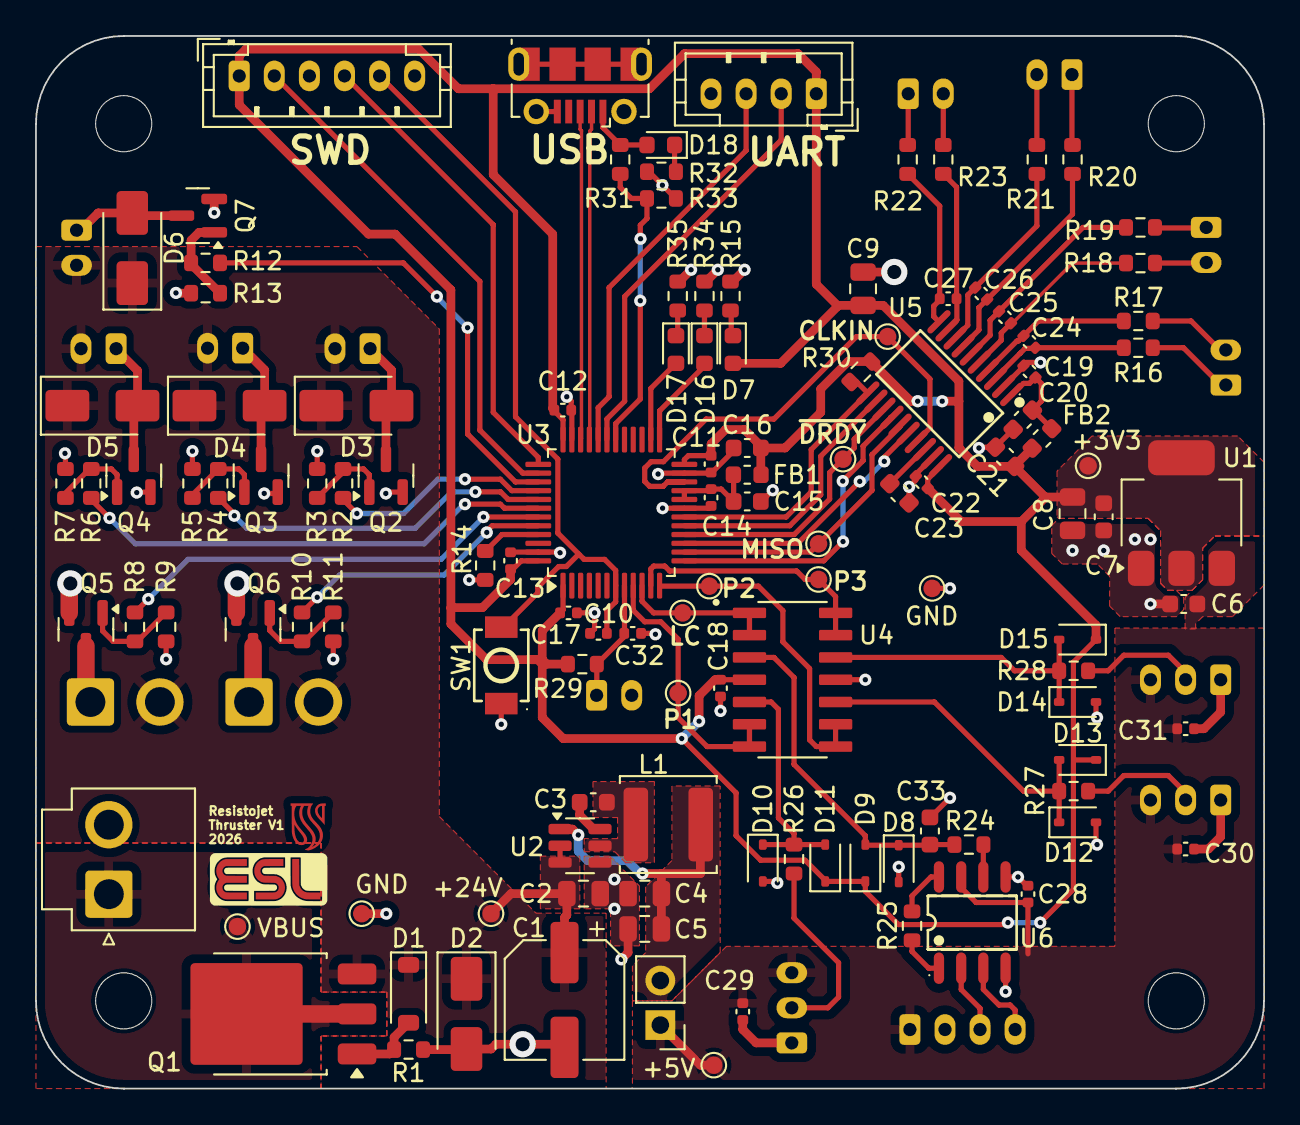
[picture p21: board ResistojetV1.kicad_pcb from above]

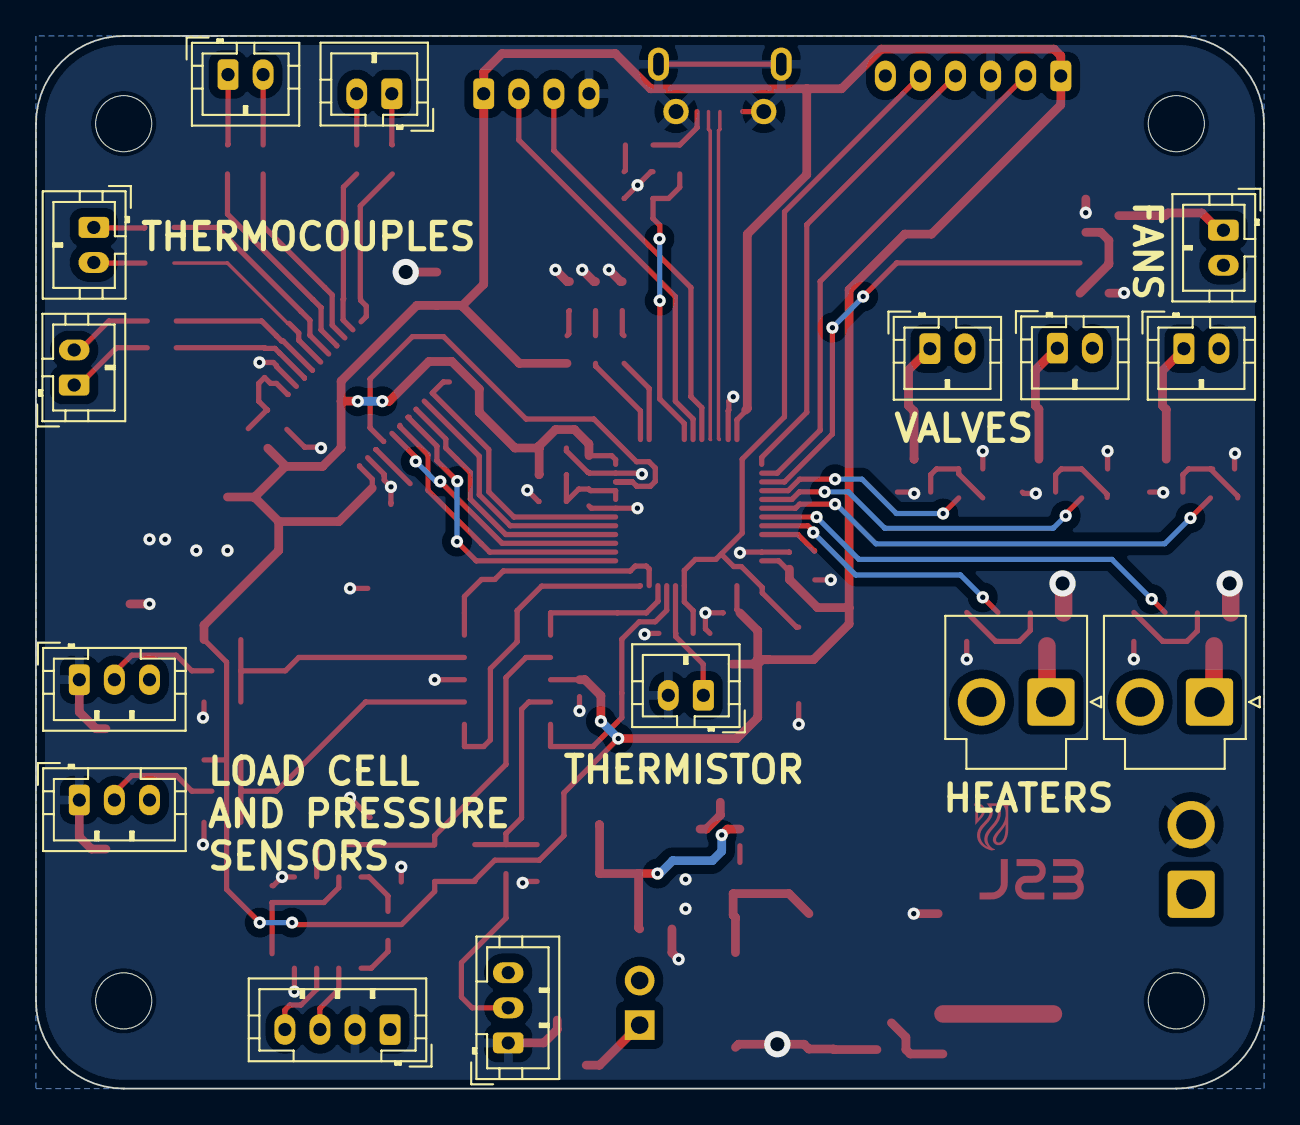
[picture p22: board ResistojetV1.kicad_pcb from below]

Board: 2 copper layers, 70.0 x 60.0 mm, 142 parts (15 on the bottom side), 86 nets.

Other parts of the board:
ESL_LOGO: LOGO
SU_LOGO: LOGO

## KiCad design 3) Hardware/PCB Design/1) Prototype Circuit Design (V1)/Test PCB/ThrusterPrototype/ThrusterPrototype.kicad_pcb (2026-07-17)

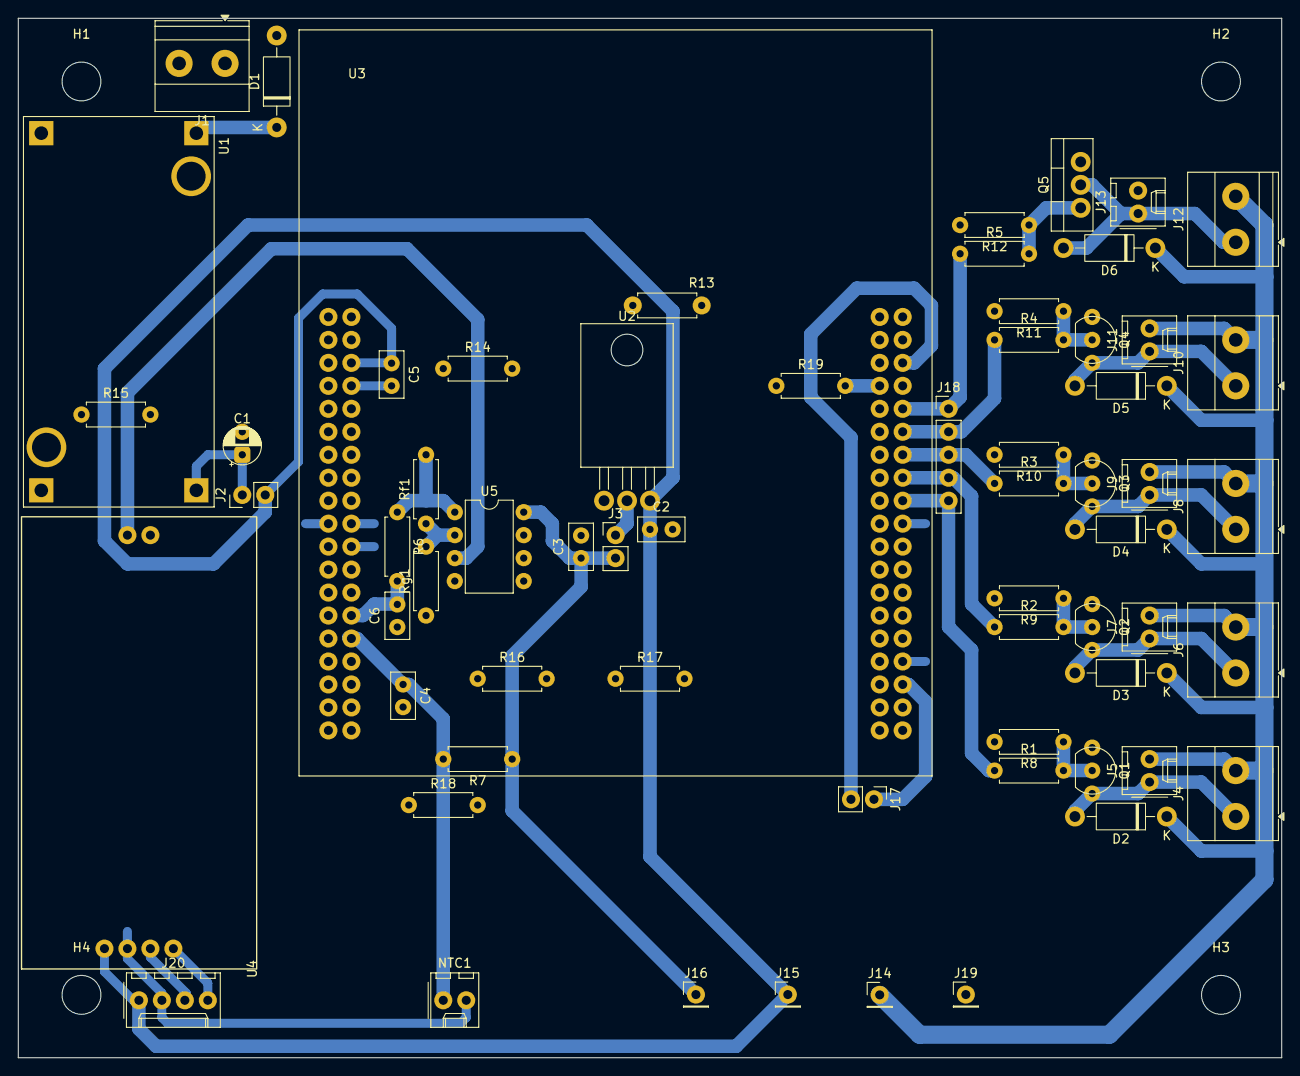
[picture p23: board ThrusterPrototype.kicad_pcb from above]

Board: 2 copper layers, 139.7 x 114.9 mm, 68 parts (0 on the bottom side), 31 nets.

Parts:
C1: 10u; CP_Radial_D4.0mm_P2.00mm
C2, C3, C4, C5: 100n; C_Disc_D5.0mm_W2.5mm_P2.50mm
C6: Clp; C_Disc_D5.0mm_W2.5mm_P2.50mm
D1, D2, D3, D4, D5, D6: 1N4007; D_DO-41_SOD81_P10.16mm_Horizontal
H1, H2, H3, H4: MountingHole; MountingHole_4.3mm_M4
J1, J4, J6, J8, J10, J12: Screw_Terminal_01x02; TerminalBlock_Phoenix_MKDS-1,5-2-5.08_1x02_P5.08mm_Horizont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
J2, J3, J17: Conn_01x02_Pin; PinHeader_1x02_P2.54mm_Vertical
J5, J7, J9, J11, J13: Conn_01x02_Pin; Molex_KK-254_AE-6410-02A_1x02_P2.54mm_Vertical
J14, J15, J16, J19: Conn_01x01_Pin; PinHeader_1x01_P2.54mm_Vertical
J18: Conn_01x05_Pin; PinHeader_1x05_P2.54mm_Vertical
J20: Conn_01x04_Pin; Molex_KK-254_AE-6410-04A_1x04_P2.54mm_Vertical
NTC1: 10k; Molex_KK-254_AE-6410-02A_1x02_P2.54mm_Vertical
Q1, Q2, Q3, Q4: 2N7000; TO-92_Inline
Q5: IRLZ44N; TO-220-3_Vertical
R1, R2, R3, R4, R5: 330; R_Axial_DIN0207_L6.3mm_D2.5mm_P7.62mm_Horizontal
R6: Rlp; R_Axial_DIN0207_L6.3mm_D2.5mm_P7.62mm_Horizontal
R7: 10k; R_Axial_DIN0207_L6.3mm_D2.5mm_P7.62mm_Horizontal
R8, R9, R10, R11, R12: 100k; R_Axial_DIN0207_L6.3mm_D2.5mm_P7.62mm_Horizontal
R13, R14, R15, R16, R17, R18, R19: 0; R_Axial_DIN0207_L6.3mm_D2.5mm_P7.62mm_Horizontal
Rf1: Rlp; R_Axial_DIN0207_L6.3mm_D2.5mm_P7.62mm_Horizontal
Rg1: Rlp; R_Axial_DIN0207_L6.3mm_D2.5mm_P7.62mm_Horizontal
U1: MC00100; CONV_MC00100
U2: LD1117V33; TO-220-3_Horizontal_TabDown
U3: NUCLEO-G0B1RE; MODULE_NUCLEO-G0B1RE
U4: Untitled
U5: MCP602; DIP-8_W7.62mm

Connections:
+3.3V: C3.1, J3.2, J16.1, R7.1, U5.8 (V+)
+5V: C2.1, C5.1, J2.2, J15.1, J20.1, U2.3 (VI), U3.CN7_6, U4.1 (VIN)
+24V: D1.2 (A), D2.1 (K), D3.1 (K), D4.1 (K), D5.1 (K), D6.1 (K), J1.1, J4.2, J5.2, J6.2, J7.2, J8.2, J9.2, J10.2, J11.2, J12.2, J13.2, J14.1
GND: C1.2, C2.2, C3.2, C4.2, C5.2, C6.1, J1.2, J19.1, J20.2, NTC1.2, Q1.1 (S), Q2.1 (S), Q3.1 (S), Q4.1 (S), Q5.3 (S), R8.2, R9.2, R10.2, R11.2, R12.2, R13.1, R13.2, R14.1, R14.2, R15.1, R15.2, R16.1, R16.2, R17.1, R17.2, R18.1, R18.2, R19.1, R19.2, Rg1.1, U1.IN-, U1.MH1 (MOUTING), U1.MH2 (MOUTING), U1.OUT-, U2.1 (GND), U3.CN7_8, U3.CN7_19, U3.CN7_20, U3.CN7_22, U3.CN10_7, U3.CN10_20, U3.CN10_32, U4.2 (GND), U4.6 (GND), U5.4 (V-)
unnamed: C4.1, NTC1.1, R7.2, U3.CN7_30 (PA1)
unnamed: C6.2, R6.2, U3.CN7_28 (PA0)
unnamed: D1.1 (K), U1.IN+
unnamed: D2.2 (A), J4.1, J5.1, Q1.3 (D)
unnamed: D3.2 (A), J6.1, J7.1, Q2.3 (D)
unnamed: D4.2 (A), J8.1, J9.1, Q3.3 (D)
unnamed: D5.2 (A), J10.1, J11.1, Q4.3 (D)
unnamed: D6.2 (A), J12.1, J13.1, Q5.2 (D)
unnamed: C1.1, J2.1, U1.OUT+
unnamed: J3.1, U2.2 (VO)
unnamed: J17.1, U3.CN10_34 (PA2)
unnamed: J17.2, U3.CN10_6 (PA3)
unnamed: J18.1, R5.1, U3.CN10_10 (PD6)
unnamed: J18.2, R4.1, U3.CN10_12 (PA12)
unnamed: J18.3, R3.1, U3.CN10_14 (PA11)
unnamed: J18.4, R2.1, U3.CN10_16 (PC1)
unnamed: J18.5, R1.1, U3.CN10_18 (PC0)
unnamed: J20.3, U4.3 (S-)
unnamed: J20.4, U4.4 (S+)
unnamed: Q1.2 (G), R1.2, R8.1
unnamed: Q2.2 (G), R2.2, R9.1
unnamed: Q3.2 (G), R3.2, R10.1
unnamed: Q4.2 (G), R4.2, R11.1
unnamed: Q5.1 (G), R5.2, R12.1
unnamed: R6.1, Rf1.2, U5.1
unnamed: U4.5 (VOUT), U5.3 (+)
unnamed: Rf1.1, Rg1.2, U5.2 (-)

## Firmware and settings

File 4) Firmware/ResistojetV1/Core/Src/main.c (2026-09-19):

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
/* Includes ------------------------------------------------------------------*/
#include "main.h"
#include "usb_device.h"

/* USER CODE BEGIN Includes */
#include "pins.h"
#include "usb.h"
#include "sensors.h"
#include "control.h"
/* USER CODE END Includes */

/* USER CODE BEGIN PD */
#define ADC1_BUFFER_SIZE 4
#define ADC2_BUFFER_SIZE 1
/* USER CODE END PD */

ADC_HandleTypeDef hadc1;
ADC_HandleTypeDef hadc2;
DMA_HandleTypeDef hdma_adc1;
DMA_HandleTypeDef hdma_adc2;

SPI_HandleTypeDef hspi1;
DMA_HandleTypeDef hdma_spi1_rx;
DMA_HandleTypeDef hdma_spi1_tx;

TIM_HandleTypeDef htim2;
TIM_HandleTypeDef htim4;
TIM_HandleTypeDef htim6;

/* USER CODE BEGIN PV */
// ADC
uint16_t adc1Buffer[ADC1_BUFFER_SIZE];
uint16_t adc2Buffer[ADC2_BUFFER_SIZE];

// Flags
uint8_t settlingFlag = 0;
uint8_t primingFlag = 0;
uint8_t firingFlag = 0;
uint8_t streamFlag = 0;
uint8_t fillValveFlag = 0;
uint8_t plenumValveFlag = 0;
uint8_t chamberValveFlag = 0;

/* USER CODE END PV */

void SystemClock_Config(void);
static void MX_GPIO_Init(void);
static void MX_DMA_Init(void);
static void MX_ADC1_Init(void);
static void MX_ADC2_Init(void);
static void MX_SPI1_Init(void);
static void MX_TIM2_Init(void);
static void MX_TIM6_Init(void);
static void MX_TIM4_Init(void);
/* USER CODE BEGIN PFP */
void thrusterStartup(void);

void sensorTask(void);
void stateTask(void);
void controlTask(void);
void valveTask(void);
void debugLEDTask(void);

float interpolateLinear(float x, float x1, float x2, float y1, float y2);
/* USER CODE END PFP */

/**
  * @brief  The application entry point.
  * @retval int
  */
int main(void)
{

  /* MCU Configuration--------------------------------------------------------*/

  /* Reset of all peripherals, Initializes the Flash interface and the Systick. */
  HAL_Init();

  /* Configure the system clock */
  SystemClock_Config();

  /* Initialize all configured peripherals */
  MX_GPIO_Init();
  MX_DMA_Init();
  MX_ADC1_Init();
  MX_ADC2_Init();
  MX_SPI1_Init();
  MX_TIM2_Init();
  MX_USB_Device_Init();
  MX_TIM6_Init();
  MX_TIM4_Init();
  /* USER CODE BEGIN 2 */
  thrusterStartup();
  /* USER CODE END 2 */

  /* Infinite loop */
  /* USER CODE BEGIN WHILE */
  while (1)
  {
	  sensorTask();
	  usbCommandTask();
	  stateTask();
	  controlTask();
	  usbStreamTask();
	  valveTask();
	  debugLEDTask();
    /* USER CODE END WHILE */

    /* USER CODE BEGIN 3 */
  }
  /* USER CODE END 3 */
}

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
/* USER CODE BEGIN 4 */
void thrusterStartup(void){
    HAL_GPIO_WritePin(FILL_VALVE_Port, FILL_VALVE_Pin, GPIO_PIN_RESET);
    HAL_GPIO_WritePin(PLENUM_VALVE_Port, PLENUM_VALVE_Pin, GPIO_PIN_RESET);
    HAL_GPIO_WritePin(CHAMBER_VALVE_Port, CHAMBER_VALVE_Pin, GPIO_PIN_RESET);

    __HAL_TIM_SET_COMPARE(&htim4, HEATER1_CHANNEL, 0);
    __HAL_TIM_SET_COMPARE(&htim4, HEATER2_CHANNEL, 0);

    HAL_TIM_PWM_Start(&htim4, HEATER1_CHANNEL);
    HAL_TIM_PWM_Start(&htim4, HEATER2_CHANNEL);

    // Initialize ADC
    HAL_TIM_Base_Start(&htim6);
    HAL_ADC_Start_DMA(&hadc1, (uint32_t *)adc1Buffer, ADC1_BUFFER_SIZE);
    HAL_ADC_Start_DMA(&hadc2, (uint32_t *)adc2Buffer, ADC2_BUFFER_SIZE);

    // Initialize ADS131M04
    HAL_TIM_PWM_Start(&htim2, ADS_CLKIN_CHANNEL);
    HAL_GPIO_WritePin(ADS_CS_Port, ADS_CS_Pin, GPIO_PIN_SET);
    HAL_GPIO_WritePin(ADS_RESET_Port, ADS_RESET_Pin, GPIO_PIN_SET);
}

void sensorTask(void){

}

void stateTask(void){
	thrusterModeHandler();
	thrusterStateHandler();
}

void controlTask(void){
	settlingFunc();
	primingFunc();
	firingFunc();
	PIDFunc();
}

void valveTask(void){
	HAL_GPIO_WritePin(FILL_VALVE_Port, FILL_VALVE_Pin,
			fillValveFlag ? GPIO_PIN_SET : GPIO_PIN_RESET);

	HAL_GPIO_WritePin(PLENUM_VALVE_Port, PLENUM_VALVE_Pin,
			plenumValveFlag ? GPIO_PIN_SET : GPIO_PIN_RESET);

	HAL_GPIO_WritePin(CHAMBER_VALVE_Port, CHAMBER_VALVE_Pin,
			chamberValveFlag ? GPIO_PIN_SET : GPIO_PIN_RESET);
}

void debugLEDTask(void){

}
/* USER CODE END 4 */
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


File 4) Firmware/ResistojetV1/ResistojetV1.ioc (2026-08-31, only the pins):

Mcu.UserName=STM32G491CCTx
PA0.Signal=ADC1_IN1
PA1.Signal=ADC1_IN2
PA11.Signal=USB_DM
PA12.Signal=USB_DP
PA13.Signal=SYS_JTMS-SWDIO
PA14.Signal=SYS_JTCK-SWCLK
PA15.Signal=GPIO_Output
PA2.Signal=ADC1_IN3
PA3.Signal=ADC1_IN4
PA4.Signal=ADC2_IN17
PA5.Signal=SPI1_SCK
PA6.Signal=SPI1_MISO
PA7.Signal=SPI1_MOSI
PA8.Signal=GPXTI8
PB0.Signal=GPXTI0
PB1.Signal=GPIO_Output
PB10.Signal=S_TIM2_CH3
PB11.Signal=GPIO_Output
PB12.Signal=GPIO_Output
PB2.Signal=GPIO_Output
PB3.Signal=GPIO_Output
PB4.Signal=GPIO_Output
PB5.Signal=GPIO_Output
PB6.Signal=S_TIM4_CH1
PB7.Signal=S_TIM4_CH2

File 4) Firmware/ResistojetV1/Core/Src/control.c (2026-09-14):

/*
 * control.c
 *
 *  Created on: Aug 31, 2026
 *      Author: Simon
 */

#include "main.h"
#include "math.h"
#include "pins.h"
#include "lookup_tables.h"
#include "control.h"
#include "sensors.h"
#include "usb.h"

// Tank pressure hysteresis thresholds (bar) to prevent state chatter
#define TANK_LOADED_PRESSURE    1.2f
#define TANK_UNLOADED_PRESSURE  1.0f
// Plenum settling criteria
#define SETTLING_PRESSURE_TOLERANCE    0.01f   // bar
#define SETTLING_TEMPERATURE_TOLERANCE 0.2f    // K
#define SETTLING_TIME                  2000    // ms
// Plenum priming criteria
#define PRIMING_PRESSURE_CORRECTION    0.05f   // bar
#define PRIMING_PRESSURE_TOLERANCE     0.05f   // bar
#define PRIMING_TEMPERATURE_TOLERANCE  1.0f    // K
#define PRIMING_TIME				   2000	   // ms
// Thruster firing criteria
#define FIRING_PRESSURE_TOLERANCE      0.05f   // bar
#define FIRING_TIME                    2000    // ms

// Thruster mode and state
ThrusterMode_t thrusterMode = MODE_EXPERIMENTAL;
ThrusterState_t thrusterState = STATE_LOADED;
PrimingStage_t primingStage = PRIMING_OFF;

// Thruster control targets
float plenumTempSetpoint = 0.0f;
float chamberTempSetpoint = 0.0f;
float plenumTargetTemp = 0.0f;
float fillPressure = 0.0f;

// Previous settling variables
uint32_t settle_last = 0;
float settle_last_pressure = 0.0f;
float settle_last_temp = 0.0f;

// Previous settling variables
uint32_t priming_last = 0;
float priming_last_temp = 0.0f;

// Previous settling variables
uint32_t firing_last = 0;
float firing_last_pressure = 0.0f;
float firing_last_temp = 0.0f;

void PIDFunc(void){}

void settlingFunc(void){
    if (!settlingFlag)
        return;
    // Empty plenum
    fillValveFlag = 0;
    plenumValveFlag = 0;
    chamberValveFlag = 1;
    // Turn off heaters
    plenumTempSetpoint = 0.0f;
    chamberTempSetpoint = 0.0f;

    uint32_t settle_now = HAL_GetTick();
    // Check for plenum stability
    if ((settle_now - settle_last) >= SETTLING_TIME){
        float settle_now_pressure = plenumPressure;
        float settle_now_temp = plenumBodyTemperature;
        if ((fabsf(settle_now_pressure - settle_last_pressure) <
             SETTLING_PRESSURE_TOLERANCE) &&
            (fabsf(settle_now_temp - settle_last_temp) <
             SETTLING_TEMPERATURE_TOLERANCE)){
            // Plenum has settled
            settlingFlag = 0;
            chamberValveFlag = 0;
        }
        settle_last = settle_now;
        settle_last_pressure = settle_now_pressure;
        settle_last_temp = settle_now_temp;
    }
}

void primingFunc(void){
	if (!primingFlag)
		return;
	switch(primingStage){
	case PRIMING_FILL:
		plenumValveFlag = 1;
		if(plenumPressure>=fillPressure-PRIMING_PRESSURE_CORRECTION){
			plenumValveFlag = 0;

		    priming_last = HAL_GetTick();
		    priming_last_temp = plenumGasTemperature;

			primingStage = PRIMING_HEAT;
		}
		break;
	case PRIMING_HEAT:
		plenumTargetTemp = proposedPlenumTargetTemp;
	    uint32_t priming_now = HAL_GetTick();
		if ((priming_now - priming_last) >= PRIMING_TIME){
			float priming_now_temp = plenumGasTemperature;
			if ((fabsf(priming_now_temp - priming_last_temp) < SETTLING_TEMPERATURE_TOLERANCE) &&
					(fabsf(priming_now_temp - plenumTargetTemp) < SETTLING_TEMPERATURE_TOLERANCE)){
				// Plenum has settled
			    primingFlag = 0;
			    primingStage = PRIMING_OFF;
			}
			priming_last = priming_now;
			priming_last_temp = priming_now_temp;
		}
	break;
	case PRIMING_OFF:
		plenumValveFlag = 0;
		primingFlag = 0;
	break;
	default:
		primingStage = PRIMING_OFF;
	break;
	}
}

void firingFunc(void){
	if (!firingFlag)
		return;
	streamFlag = 1; // Stream experimental data
	fillValveFlag = 0;
	plenumValveFlag = 0;
	chamberValveFlag = 1; // Fire thruster

    uint32_t firing_now = HAL_GetTick();
    // Check for plenum stability
    if ((firing_now - firing_last) >= FIRING_TIME){
        float firing_now_pressure = plenumPressure;
        if (fabsf(firing_now_pressure - firing_last_pressure) <
             FIRING_PRESSURE_TOLERANCE){
            // Plenum has settled
            firingFlag = 0;
            streamFlag = 0;
            chamberValveFlag = 0;
        }
        firing_last = firing_now;
        firing_last_pressure = firing_now_pressure;
    }
}

const char *thrusterModeToString(ThrusterMode_t mode)
{
    switch (mode)
    {
    case MODE_EXPERIMENTAL:
        return "EXPERIMENTAL";

    case MODE_MANUAL:
        return "MANUAL";

    case MODE_RESTRICTED_MANUAL:
        return "RESTRICTED_MANUAL";

    default:
        return "UNKNOWN";
    }
}

const char *thrusterStateToString(ThrusterState_t state)
{
    switch (state)
    {
    case STATE_LOADED:
        return "LOADED";

    case STATE_UNLOADED:
        return "UNLOADED";

    case STATE_SETTLING:
        return "SETTLING";
    case STATE_SETTLED:
        return "SETTLED";

    case STATE_PRIMING:
        return "PRIMING";

    case STATE_PRIMED:
        return "PRIMED";

    case STATE_FIRING:
        return "FIRING";

    case STATE_ABORT:
        return "ABORT";

    default:
        return "UNKNOWN";
    }
}

/* The thruster mode handler must be executed first in the system while
 loop because the state handler clears the manual request flag */
void thrusterModeHandler(void){
	switch(thrusterMode)
	{
	case MODE_EXPERIMENTAL:
		if (manualRequest && (tankPressure > TANK_LOADED_PRESSURE))
			thrusterMode = MODE_RESTRICTED_MANUAL;
		else if (manualRequest && (tankPressure < TANK_UNLOADED_PRESSURE))
			thrusterMode = MODE_MANUAL;
		break;
	case MODE_MANUAL:
		if (tankPressure > TANK_LOADED_PRESSURE)
			thrusterMode = MODE_RESTRICTED_MANUAL;
		if (experimentalRequest && fillValveFlag == 0)
			thrusterMode = MODE_EXPERIMENTAL;
		break;
	case MODE_RESTRICTED_MANUAL:
		if (tankPressure < TANK_UNLOADED_PRESSURE)
			thrusterMode = MODE_MANUAL;
	    if (experimentalRequest &&
	    		plenumValveFlag == 0 &&
				chamberValveFlag == 0)
	    	thrusterMode = MODE_EXPERIMENTAL;
		break;
	}
}
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

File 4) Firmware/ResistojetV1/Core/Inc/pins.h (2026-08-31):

/*
 * pins.h
 *
 *  Created on: Aug 26, 2026
 *      Author: Simon
 */

#ifndef INC_PINS_H_
#define INC_PINS_H_

#include "main.h"

/* Valve pins */
#define FILL_VALVE_Port         GPIOB
#define FILL_VALVE_Pin          GPIO_PIN_3
#define PLENUM_VALVE_Port       GPIOB
#define PLENUM_VALVE_Pin        GPIO_PIN_4
#define CHAMBER_VALVE_Port      GPIOB
#define CHAMBER_VALVE_Pin       GPIO_PIN_5

/* Debug LED pins */
#define LED1_Port               GPIOB
#define LED1_Pin                GPIO_PIN_11
#define LED2_Port               GPIOB
#define LED2_Pin                GPIO_PIN_12

/* Heater PWM channels */
#define HEATER1_Port            GPIOB
#define HEATER1_Pin             GPIO_PIN_6
#define HEATER1_CHANNEL         TIM_CHANNEL_1
#define HEATER2_Port            GPIOB
#define HEATER2_Pin             GPIO_PIN_7
#define HEATER2_CHANNEL         TIM_CHANNEL_2

/* ADC pins */
#define ADC1_THERMISTOR_INDEX   0
#define ADC1_PRESSURE1_INDEX    1
#define ADC1_LOADCELL_INDEX     2
#define ADC1_PRESSURE3_INDEX    3
#define ADC2_PRESSURE2_INDEX    0

#define THERMISTOR_Port         GPIOA
#define THERMISTOR_Pin          GPIO_PIN_0
#define PRESSURE1_Port          GPIOA
#define PRESSURE1_Pin           GPIO_PIN_1
#define LOADCELL_Port           GPIOA
#define LOADCELL_Pin            GPIO_PIN_2
#define PRESSURE3_Port          GPIOA
#define PRESSURE3_Pin           GPIO_PIN_3
#define PRESSURE2_Port          GPIOA
#define PRESSURE2_Pin           GPIO_PIN_4

/* ADS131M04 pins */
#define ADS_SCLK_Port           GPIOA
#define ADS_SCLK_Pin            GPIO_PIN_5
#define ADS_MISO_Port           GPIOA
#define ADS_MISO_Pin            GPIO_PIN_6
#define ADS_MOSI_Port           GPIOA
#define ADS_MOSI_Pin            GPIO_PIN_7

#define ADS_DRDY_Port           GPIOB
#define ADS_DRDY_Pin            GPIO_PIN_0
#define ADS_CS_Port             GPIOB
#define ADS_CS_Pin              GPIO_PIN_1
#define ADS_RESET_Port          GPIOB
#define ADS_RESET_Pin           GPIO_PIN_2

#define ADS_CLKIN_Port          GPIOB
#define ADS_CLKIN_Pin           GPIO_PIN_10
#define ADS_CLKIN_CHANNEL       TIM_CHANNEL_3

#endif /* INC_PINS_H_ */

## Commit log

2026-07-17 Add resistojet project files
    [0,250' NPT TEE.ipt, 0.4 nozzle.ipt, 0101_08_13.0003.ipt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]
2026-07-22 Add CFD simulations, RGP generator, and project updates
    [Creality Heatsink v1.2.ipt, Heatbreak CR30.ipt, Heater.0002.ipt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]
2026-07-22 Set up real gas CFD case file
2026-08-06 Continued development of the mechanical and electronics of prototype thruster
    [100g_load_cell.ipt, 103hss1_4.ipt, 119hss1_4x1_8.ipt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]
2026-08-11 Finished Routing Thruster V3 PCB
    [ThrusterV3.kicad_pcb, ThrusterV3.kicad_sch]
2026-08-23 Finished PCB, prepared production files, and started firmware development
    [0,250' NPT TEE.ipt, 0.4 nozzle.ipt, 0101_08_13.0003.ipt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]
2026-08-31 Further firmware pin labels and USB functionality additions
    [ResistojetV1.kicad_pcb]
2026-09-10 further firmware progress
    [ResistojetPrototype.0020.iam, ResistojetPrototype.0021.iam, ResistojetPrototype.iam]
2026-09-14 Revisions made to final model for manufacturability; firmware additions
    [Nozzle_JLC.0003.idw, Nozzle_JLC.0012.ipt, Nozzle_JLC.idw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]
2026-09-15 Prototype mechanical parts fully selected
    [1-4 NPT 4 Way Cross Pneumatic Fitting.ipt, 103hss1_4.ipt, 119hss1_4x1_8.ipt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]
2026-09-19 Finish loadcell lever design; started sensor (ADS131M04) firmware
    [Loadcell_lever.0001.ipt, Loadcell_lever.0003.ipt, Loadcell_lever.0004.ipt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]

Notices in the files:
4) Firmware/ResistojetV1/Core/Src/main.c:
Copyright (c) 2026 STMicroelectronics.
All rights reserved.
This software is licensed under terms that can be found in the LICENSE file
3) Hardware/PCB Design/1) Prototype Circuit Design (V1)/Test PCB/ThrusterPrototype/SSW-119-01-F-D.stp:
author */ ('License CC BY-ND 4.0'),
